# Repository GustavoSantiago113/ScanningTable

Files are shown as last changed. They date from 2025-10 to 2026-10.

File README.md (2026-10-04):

<div align="center">

# 3D Reconstruction of Small Objects

**Non-official implementation and adaptation of the paper: [Automated Low-Cost Photogrammetric Acquisition of 3D Models from Small Form-Factor Artefacts](https://www.mdpi.com/2079-9292/8/12/1441), from Collins et al., 2019**

**Note:** This implementation was performed in a **Linux** environment, with GPU with CUDA acceleration.

</div>

---

- [3D Reconstruction of Small Objects](#3d-reconstruction-of-small-objects)
- [Step 1 - Image Acquisiton hardware](#step-1---image-acquisiton-hardware)
- [Step 2 - Acquisition Software](#step-2---acquisition-software)
- [Step 3 - Taking Images](#step-3---taking-images)
- [Step 4 - Camera Geometry Estimation](#step-4---camera-geometry-estimation)
- [Step 5 - Dense Point Cloud Reconstruction](#step-5---dense-point-cloud-reconstruction)
- [Step 6 - Cropping](#step-6---cropping)
- [Step 7 - Point Cloud Registration](#step-7---point-cloud-registration)
- [Step 8 - Meshing](#step-8---meshing)
- [Step 9 - Texturing](#step-9---texturing)
- [Running the whole pipeline in one go](#running-the-whole-pipeline-in-one-go)

---

# Step 1 - Image Acquisiton hardware

For the table, I 3D modeled and printed a structure for it. It has a base and a top plate. You can find the models in the folder [3DFiles](3DFiles/). You can print it in the way you prefer, but I recommend using PLA, 3 layers of wall width, 20% fill, and 0.2mm layer height. To aid in the table movement, I added **3 2809 bearings.** To fix the motor in place, I used 2 3mm bolts.

The pseudo-random calibration pattern was made using a code in Python, available at the file [generate_pattern.py](utils/generate_pattern.py). It generates the pattern of a 130x130 mm square with 52 squares at each side, and saves as an image.

For the hardware, I used a 28BYJ-48 Stepper Motor with a ULN2003AN DIP-16 Driver. To connect with the phone and control the motor, I am using a Wemos D1 Mini ESP8266 Board. To power it, I am using a 9V power supply and a L7805 voltage regulator, with some capacitors. To connect everything, I made a custom PCB. The bill of materials, schematics and gerber files are in the folder [PCB](PCB/).

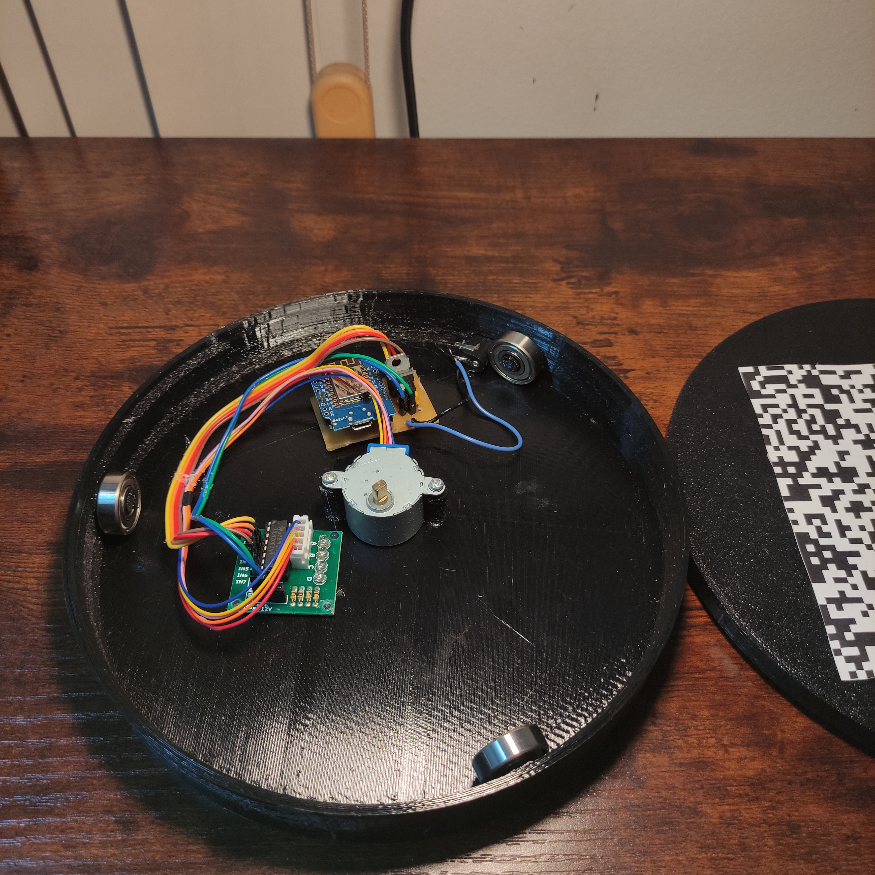
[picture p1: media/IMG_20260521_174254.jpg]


For the lights, I followed the same method as described by the paper, with a desk lamp at 20 cm perpendicullarly appart from the rotating plate **using a cold, white LED**.

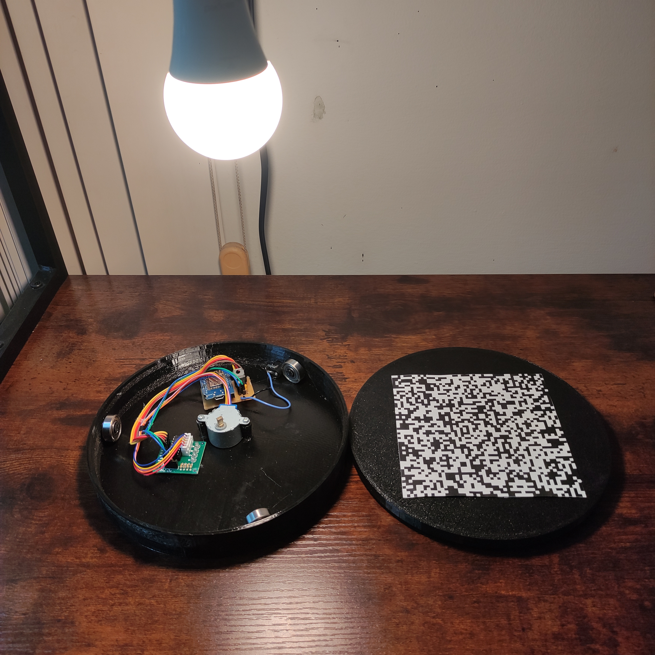
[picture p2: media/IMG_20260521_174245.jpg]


To support the phone, I used the tripod design found in ThingIverse: https://www.thingiverse.com/thing:2423960/files . The files are also in the [3DFiles folder](3DFiles)

# Step 2 - Acquisition Software

The script to run the ESP8266 is available at [ESP8266.ino](ESP8266\ESP8266.ino). The number of rotations is fixed on 36 (10 degree interval). The ESP creates a WebServer, with a Wi-Fi name and a password. The app sends requests to the ESP, such as: `start`, `stop`, and `continue`. The ESP sends the command `waiting` to the app so it knows when to take the picture.

The [app](scanning_table_app) was made in *Flutter* and **tested on an Android device only**. It has a initial page, only allowing to move to the next page (taking pictures) when the cellphone is connected to the ESP. To start scanning the user first must to choose the folder where the images are going to be saved. After that, the user can click on `Scan` and the app + ESP does the rest automatically. If something goes wrong, the user can click on `stop`, and the operation will be stopped.

Each photo is saved as `<scan>_stop_<stop>_<timestamp>.jpg`, e.g. `01_stop_03_20260703_163620.jpg` - `<scan>` numbers each full rotation sequence within the current app session (`01` for the first press of `Scan`, `02` for the second, and so on) and resets back to `01` every time the app is (re)started, so photos from different scans in the same folder never collide or get mixed up.

The camera settings in the app are following the paper description:
- Apperture of f/1.2;
- Shutter speed of 1/4s;
- ISO 200;

**Important reminder: to connect with the ESP, the mobile data must be turned off**

# Step 3 - Taking Images

The camera was positioned a little bit different than described in the paper. Instead of at 40 degrees to the table and at 25cm distant, as describred, the images were took framing the whole calibration pattern, at less than 40 degrees. The reason for this is that phones have different focals, meaning that the images from different phones will become different, even if you keep the same parameters. *When doing this on your phone, try to make the board occupy the maximum of the image as possible and at low angles*. See an example of the virtual image, where you must try to mimic its position in the real picture:

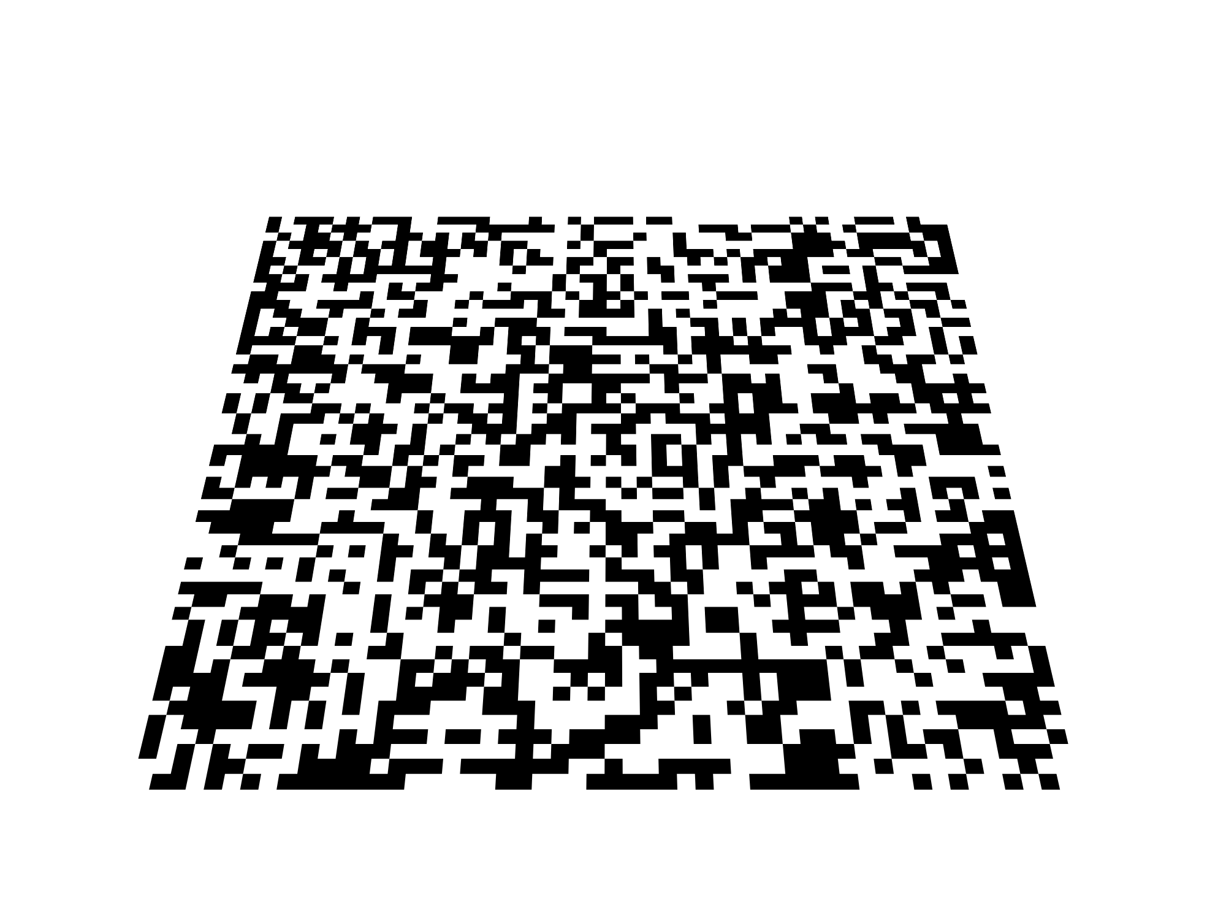
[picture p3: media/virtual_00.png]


Just like in the paper, I took some sets of different angles of the object (a 32mm scale minitature painted by me). The sets are in the folder [images](images/). Some examples:

**<center>Set 1:**

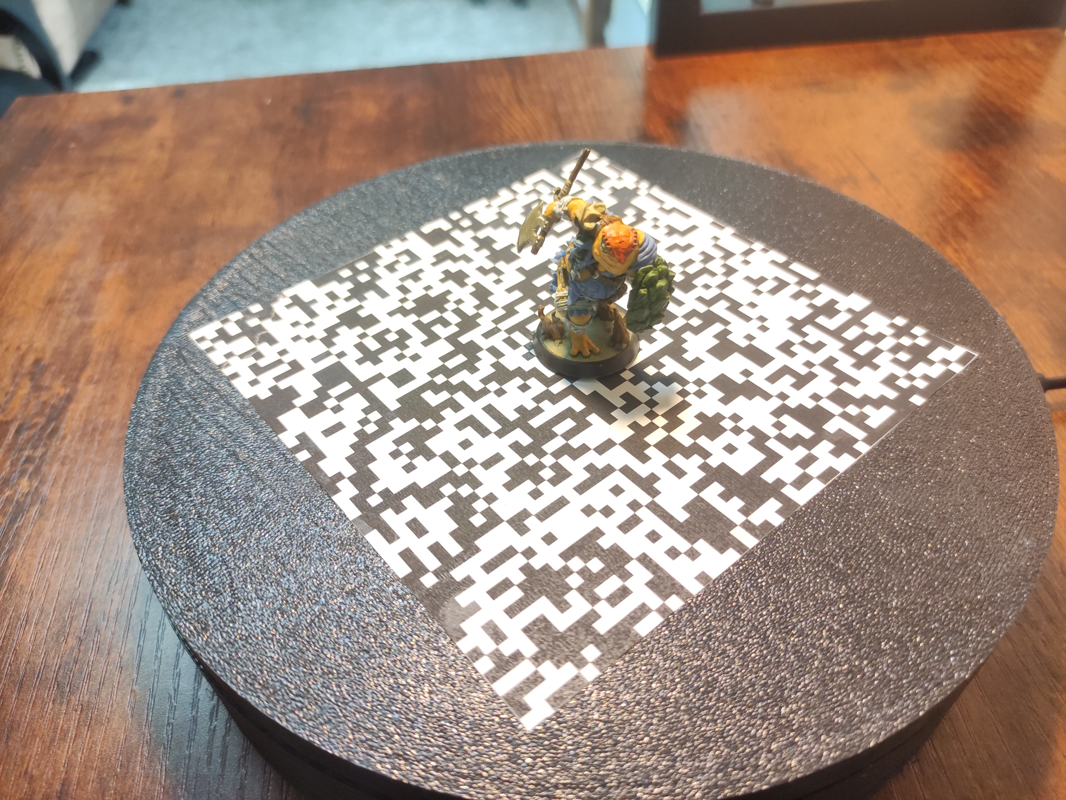
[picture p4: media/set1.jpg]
</center>

**<center>Set 2:**

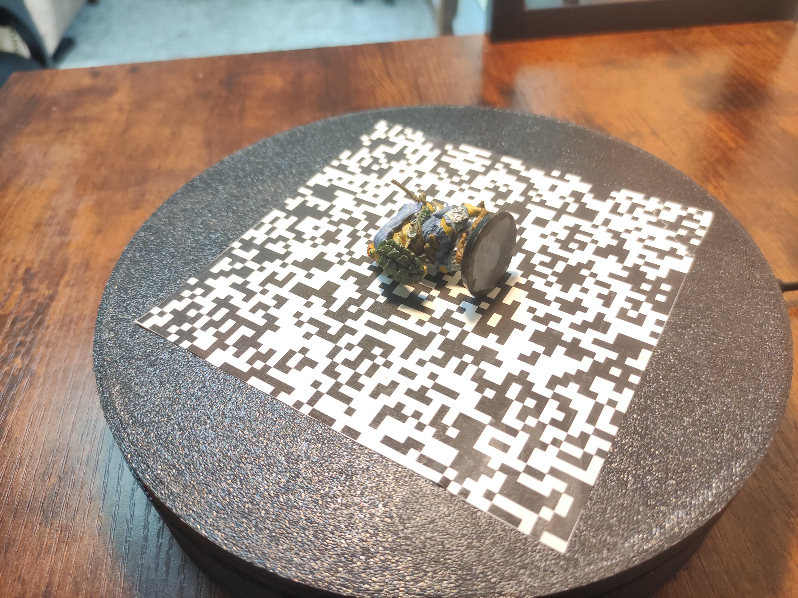
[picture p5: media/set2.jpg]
</center>

**<center>Set 3:**

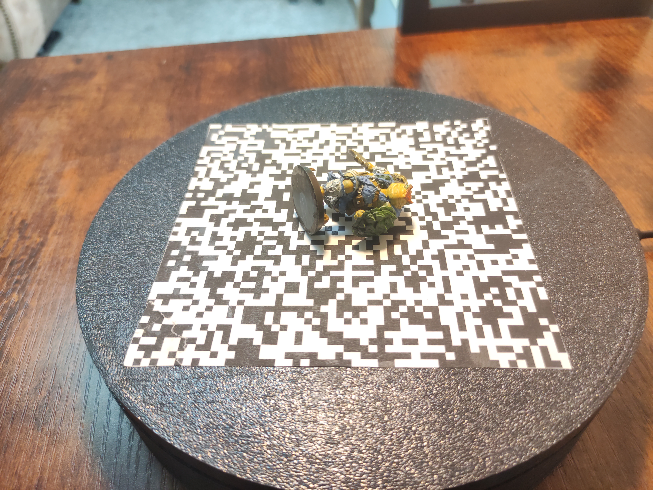
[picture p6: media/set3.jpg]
</center>

# Step 4 - Camera Geometry Estimation

Implemented in [camera_geometry_estimation.ipynb](camera_geometry_estimation.ipynb), using [pycolmap with cuda](https://github.com/colmap/pycolmap) for feature extraction, matching and bundle
adjustment - SIFT extraction and matching both run on the GPU (`pycolmap.Device.cuda`) explicitly,
not just via bundle adjustment's own solver, trading a small amount of run-to-run reproducibility
(GPU SIFT's extraction order isn't as tightly controlled as the CPU path's) for materially faster
extraction/matching; see `colmap_calibration.build_database`'s own docstring if byte-identical
results across runs matter more than that speed. The pipeline follows the paper: a sequence of virtual "photographs" of the calibration
plate is rendered from known viewpoints (paper spec: 12 views, 30&deg; apart, 45&deg; elevation;
the notebook defaults to 24 views/15&deg; steps for denser real-photo coverage - see its parameters
cell to reproduce the literal paper spec), registered with COLMAP at their exact known
intrinsics/pose, and used as a fixed calibration model that the real photographs are localised
against via incremental bundle adjustment (`fix_existing_frames` + `constant_cameras` keep the
virtual poses/intrinsics fixed throughout; only the real cameras are refined). A final
retriangulation pass (using every registered camera, not just the virtual ones) then fills out the
sparse point cloud with the artefact's own geometry, not just the calibration plate, before the
virtual photographs are removed, leaving calibrated real cameras plus a sparse point cloud ready
for dense reconstruction.

Not every real photograph is guaranteed to register - the notebook reports how many did, and is
intentionally bounded to a fixed runtime (`MAX_RUNTIME_SECONDS`, `MAX_REG_TRIALS=1`) rather than
retrying indefinitely. Registration also includes plausibility filters (implausible
camera-to-plate distance, near-duplicate positions from COLMAP's linear solver failing on a
poorly-conditioned planar-target fit) that discard failed estimates rather than keep them.

`reconstruct.py` adds a few robustness steps on top of the notebook:

- **Focal-length prior from the plate.** A homography between several photos and the flat pattern
  gives the real camera's focal length (Zhang's plane constraints). EXIF is only the fallback.
- **Resolution search.** Registration is retried at long edges from 1500px up to `--max-long-edge`
  (smallest first) until more than 30 photos register. If nothing registers at any size, the
  search runs again with exact (brute-force) matching.
- **Orbit check.** An attempt whose cameras' heights spread more than 40mm is rejected, because one
  camera on a turntable traces a horizontal circle.
- **Orbit filling.** Photos COLMAP still couldn't place are posed by rotating their registered
  neighbours about the fitted turntable axis. This uses the stop index in the file name
  (`..._stop_07_...jpg`).

Dense stereo still runs at `--max-long-edge`: the calibrated cameras are rescaled to that size.

# Step 5 - Dense Point Cloud Reconstruction

Implemented in [dense_reconstruction.ipynb](dense_reconstruction.ipynb). The paper uses CMVS/PMVS
(Furukawa's clustering-views-for-multi-view-stereo toolchain) for this step. That toolchain has no
pip package, is unmaintained, and COLMAP's own docs describe it as superseded by COLMAP's own dense
pipeline - **PatchMatchStereo** (per-image depth/normal maps) followed by **StereoFusion** (merging
those into one point cloud) - which this notebook uses instead, via the same `pycolmap` library
already used for calibration.

The pipeline: load Step 4's calibrated real cameras and reuse the exact downscaled photographs it
already calibrated against (`outputs/<set>/work`, no separate re-downscale needed) &rarr; undistort
into a COLMAP dense workspace &rarr; PatchMatchStereo for per-image depth/normal maps &rarr;
StereoFusion into one dense, coloured point cloud &rarr; restrict to a rough region of interest
around the artefact (not the paper's dedicated cropping stage, which comes later) &rarr; attempt to
downsample towards target point densities (points per mm&sup2; of the ROI's bounding-box surface
area, standing in for actual surface area until a mesh exists).

**On target density**: this step was scoped for 100 and 300 points/mm&sup2;. Validated on `set_1`
(35 photos, downscaled to 2000x1500 as Step 4 left them), the achieved density came out to
**~6 points/mm&sup2;** - one to two orders of magnitude below either target. The notebook keeps
both targets as explicit parameters and reports the honest gap (via
`dense_reconstruction.downsample_to_density`'s `reached_target=False` path) rather than silently
substituting a different number or fabricating points a camera never actually resolved. This is a
property of the input photos (phone camera, ~20-25cm working distance, downscaled for tractable
runtime) more than the algorithm - raising Step 4's `MAX_LONG_EDGE` (more pixels on the artefact per
photo) and/or taking more, closer photos would likely close some of that gap, at the cost of a much
longer `PatchMatchStereo` runtime (full 4000x3000 photos measured ~60-90s/image on the dev GPU,
vs. ~35 minutes total for all of `set_1` at 2000x1500). Even though the poits density were not as high as stated in the paper, the reconstruction level of details is *impressive*.

# Step 6 - Cropping

Implemented in [cropping.ipynb](cropping.ipynb). An axis-aligned crop box with x/y extent equal
to the calibration pattern's own size (130&times;130&nbsp;mm, centred at the world origin, since
the calibration model is defined at z&nbsp;=&nbsp;0), and a **fixed** z lower-limit of
2&nbsp;mm above the turntable.

The paper's own method for the lower limit is a *search*, not a fixed offset: slide a 1mm slab
upward from 2mm above the turntable, averaging point luminosity, until it crosses a threshold -
below that z is dark supporting material, above it the lighter artefact. That's the right method
for a setup that actually hides the object on dark foam. This implementation's own captures
(`set_1`, `set_2`) don't use any, though: measured directly against the real data, the printed
pattern is one dominant, bright, neutral-grey point mass right at z&nbsp;=&nbsp;0, and the
artefact's own material begins immediately above it (over a 100x point-count drop between z=0 and
z=1mm) - there's no separate dark material to search for, so the fixed 2mm offset is used
directly instead. The luminosity search (`cropping.find_lower_z_limit`) is still implemented and
correct; it just isn't called by `reconstruct.py`'s pipeline by default any more, because on this
project's own real data it actively mis-fired - see the next bullet.

Four things came up validating this against real data (`set_1`-`set_3`) that the paper's setup
doesn't need to deal with:

- **Level the turntable tilt**. Not in the paper, added for this implementation: the
   calibration model fixes the pattern at world Z&nbsp;=&nbsp;0 by construction, but the *real*,
   physically captured turntable doesn't have to be level in that same frame, and the z-based
   crop assumes it is. A RANSAC plane fit finds the real pattern/turntable plane and the
   cloud is rotated so that plane sits back at Z&nbsp;=&nbsp;0.
- **A Step 4 orientation bug.** This implementation's real-camera reconstruction comes out mirrored
  through the z&nbsp;=&nbsp;0 plane - the artefact reconstructs *below* the turntable instead of
  above it, almost certainly Step 4's own coplanar-target pose ambiguity (see
  `plate_geometry.look_at_origin`'s docstring) resolving to the wrong sign for this rig.
  `cropping.correct_z_axis_inversion` negates z as a workaround at the data-consumption end so the
  rest of the crop logic (written straight from the paper, which assumes the artefact sits above
  the turntable) applies correctly. The proper fix belongs in `colmap_calibration.py`'s pose
  disambiguation, not here.
- **A z upper-limit isn't in the paper**, but was added here because this implementation's dense
  reconstruction consistently leaves one small clump of disconnected debris floating well above
  the artefact (likely a specular-highlight fusion ghost) - visible as a gap in point density
  between the artefact's own tapering mass and that clump. `cropping.find_upper_z_limit` cuts at
  the first sufficiently-thick run of near-empty slices above the lower limit. It's a narrow,
  generic density-gap heuristic, not a general outlier remover.

# Step 7 - Point Cloud Registration

Implemented in [point_cloud_registration.ipynb](point_cloud_registration.ipynb). This covers the
paper's full Section 2.4.4 - registration *and* the confidence-weighted merge it also describes,
since the paper treats both under one heading. Each of `set_1`-`set_3` was captured with the
object resting differently on the turntable, so Step 6's three cropped point-clouds are genuine
partial views, each in its own independent frame, that need combining:

1. **Coarse alignment** - paper spec: Super4PCS. No maintained pip package or Python binding
   exists for either 4PCS or Super4PCS, so `utils/registration.py`'s `coarse_align` implements the
   same family of algorithm from scratch: a RANSAC search over congruent point triples (matching
   pairwise distances, scored by largest-common-pointset overlap) rather than Mellado et al.'s
   specific coplanar-4-point/smart-indexing formulation - that indexing is what makes Super4PCS
   *fast*; it doesn't change what a correct coarse alignment looks like.
2. **Fine alignment** - a Weighted ICP (`weighted_icp`), exactly as described: each nearest-
   neighbour correspondence is weighted by the product of its two points' confidence values
   (Equation 3), so precisely-reconstructed points dominate the fit.
3. **Confidence** (Equation 2) needs a per-point surface normal, which Step 5's `pycolmap`-based
   dense reconstruction doesn't preserve (its `Reconstruction` object drops the photo-consistency
   normals PatchMatchStereo/StereoFusion compute internally). `estimate_normals` substitutes a
   standard PCA-over-local-neighbours normal, oriented outward from the cloud's own centroid.
4. **Merge** (Equation 4): once registered, close point pairs across clouds are confidence-
   weighted-interpolated into one rather than kept as two redundant, possibly conflicting points;
   unique points are kept as-is. This also does this implementation's pruning - there's no separate
   pruning stage.

# Step 8 - Meshing

Implemented in [meshing.ipynb](meshing.ipynb) via `utils/meshing.py`, following the paper's
Section 2.4.5 directly:

> Following the point-cloud registration and merging operations described above, the points
> require connecting to form a surface mesh before texturing can be applied. Poisson surface
> reconstruction was used for this stage and was chosen for its relative simplicity and
> reliability. Some care is needed to avoid loss of detail on inscribed surfaces. We found that
> an octree depth of 14 gave a good compromise, retaining the detail of the inscriptions with a
> tractable computational complexity.

Poisson reconstruction itself runs via `pycolmap.poisson_meshing`, COLMAP's own binding around
Kazhdan's reference PoissonRecon implementation - not `open3d`, which this implementation used
originally (`open3d` is still used for point-cloud/mesh I/O and cleanup). Two things came up
switching to it, both specific to running on this project's WSL development machine rather than
algorithmic:

- **`num_threads` has to stay pinned at 1.** Left at COLMAP's own default (`-1`, all cores),
  `pycolmap.poisson_meshing` hangs on this machine - a trivial depth-6 smoke test went from 0.9s
  at `num_threads=1` to 43s at full multithreading, and a depth-14 run at realistic point-cloud
  scale (250,000 points) was still running after 10+ minutes (pegging ~18 of the machine's 20
  cores) before being killed. This mirrors an already-known problem: `pymeshlab`'s own Poisson
  filter was tried and rejected earlier in this project for the same class of issue (see the
  Texturing section below) - sustained multithreaded load repeatedly correlating with this WSL
  instance's own instability. Pinned to `num_threads=1`, the same depth-14/250k-point run finishes
  in ~70.6s, against ~128s for the `open3d` path it replaced - faster as well as reliable.

- **COLMAP's own trim step corrupts output at this project's data scale.** `PoissonMeshingOptions`
  exposes a `trim` parameter (a density threshold for its own low-confidence-vertex removal), but
  every nonzero value tested - including deliberately tiny ones - produced NaN and huge-magnitude
  (>1000, against a true bounding box of order 100mm) vertex positions. This isn't a case of
  picking a bad absolute number: on a realistic mm-scale test cloud, `trim=10.0` (the library's
  own default) corrupted 86% of output vertices, while `trim=1.0` on the *same* cloud was
  completely clean - the correct value is scale/density-dependent in a way this build gives no
  safe way to discover in advance, and a wrong one corrupts silently rather than erroring.
  `trim=0.0` (disabling the step outright) was the only value verified clean at every scale
  tested, so that's what's hardcoded - which also means the returned mesh carries no per-vertex
  density estimate the way `open3d`'s binding did.

One thing came up building the original `open3d`-based version against real data, and still
applies:

- **Poisson reconstructs a phantom "bubble" surface.** Poisson fits one *global* implicit
  function across the whole point-cloud, so even a handful of points far from everything else -
  each still gets a plausible local normal - can pull that function's zero-level-set out into a
  sizeable, completely disconnected surface floating in empty space. Diagnosed on this implementation's
  own merged cloud: 67,805 of 67,820 points form one connected component at a 1.5mm radius, and
  the rest are 1-4-point fragments (registration/fusion debris, not real geometry) scattered
  elsewhere. `meshing.remove_isolated_points` removes those from the *point-cloud*, before Poisson
  ever sees them, rather than trying to identify and trim the mesh it produces from them
  afterwards - which needs the (expensive) reconstruction to have already run once just to find
  out.

- **Thin, sparsely-sampled structures balloon into a "blob" instead of meshing thin.** This is a
  different failure from the bubble above - it happens even on a clean point-cloud with no
  disconnected debris. Poisson's single global implicit function has to produce *something*
  wherever point density drops, and where it drops enough (a narrow base, a thin protrusion),
  the reconstructed surface doesn't taper down with it - it extrapolates past the last real point
  and rounds out into a smooth bulge with nothing behind it. Diagnosed on a real scan with a
  sparsely-sampled base (using the original `open3d`-based Poisson, which still returned a density
  estimate): the raw mesh's z-range extended ~16mm past the point-cloud's own lowest point, and
  every one of those extrapolated vertices fell in the bottom ~3.5% of Poisson's own per-vertex
  density estimate. Low density isn't the same as thin-but-real, though - it flags *unsupported
  extrapolation* specifically. Since switching to `pycolmap.poisson_meshing` gives up that density
  estimate (see above), `meshing.trim_unsupported_vertices` now flags the same failure mode with a
  differently-sourced signal instead: each mesh vertex's KD-tree distance to the nearest real point
  in the input cloud, dropping the `quantile` fraction farthest from any real point (default
  `quantile=0.02`) - the two metrics should behave similarly (both are low exactly where the input
  cloud's own support is thin), but this specific metric/threshold pairing hasn't yet been
  re-validated against real captures the way the density-based version was. Cutting vertices out of
  the mesh's middle leaves small disconnected shell fragments along the cut;
  `meshing.remove_small_mesh_components` clears those by keeping only connected triangle components
  of at least `min_triangles` (default `100`) - on the scan above, 1,522 components dropped to
  ~130, and the ones removed made up under 1% of the mesh's total triangles.

# Step 9 - Texturing

Implemented in [texturing.ipynb](texturing.ipynb) via `utils/texturing.py`, following the
paper's Section 2.4.6: project the original photographs onto Step 8's mesh using the camera
positions from Step 4's calibration. Each registered real camera is carried through this
implementation's own Step 4 &rarr; Step 8 chain into the mesh's common frame - this implementation's version
of the paper's "VmnMn" (camera Vmn transformed by the per-acquisition model-matrix Mn):

- **The z-axis correction has no valid rigid-body camera analogue.** Step 6 corrects the
  *points* by negating z outright (`cropping.correct_z_axis_inversion`) - a reflection, not a
  rotation, so there's no way to move a *camera* the same way and still call the result a
  physically normal camera. `texturing.flip_z_camera_pose` derives the (improper, but
  correctly-reprojecting) substitute instead: composing the original camera rotation with the
  z-flip *on the right* reprojects corrected-frame points onto exactly the same pixels the
  original, unmirrored camera always did, even though the resulting matrix has det = -1. This
  was validated against this implementation's own real cameras, not just derived on paper: repositioned
  into the mesh's common frame, all 100 registered real cameras across the three sets look at
  the mesh's own centroid to within about 6-10&deg; (the notebook's own sanity-check step) -
  before landing on this formula, they were off by ~173&deg;, i.e. facing almost exactly
  backwards.
- **Step 7's registration transform** carries the camera the same way
  `registration.apply_transform` carries points (`texturing.compose_with_registration`).

The paper's own tool for this step is MeshLab (via UV-atlas texturing from registered
cameras). `pymeshlab`'s equivalent filter turned out to be broken under headless/server
execution in this environment (a long-standing, version-spanning upstream issue, not specific
to this setup), so this implementation instead uses `open3d` (already a project dependency,
`meshing.py`) to project every registered, undistorted photo directly onto the mesh and paint
each *vertex* with the occlusion-aware, multi-view-blended result - not a UV-mapped texture
atlas, but real photographic colour, correctly occlusion-tested per camera via `open3d`'s own
`RaycastingScene` (Embree-backed, CPU-only). Two things needed correcting empirically before
this was trustworthy, not just plausible-looking - both documented in
`texturing.texture_mesh_vertex_colors`'s own docstring:

- **Ray direction.** Casting the occlusion ray *from* each vertex *towards* the camera
  routinely self-intersects an adjacent triangle at t &asymp; 0 ("shadow acne") - this mesh is
  not watertight or edge-manifold (`mesh.is_watertight()` is `False`), so no fixed offset
  reliably escaped it. Casting *from the camera towards* the vertex instead avoids the problem
  entirely (the ray origin is never near the mesh surface) and doubles as a proper z-buffer-style
  visibility test.
- **Occlusion tolerance.** Initially rejected a vertex whenever the ray hit anything before
  reaching it, which - audited directly against this implementation's own mesh - was rejecting even
  vertices whose normals point almost exactly at the camera. Tracing a few of those hits showed
  real geometry several mm to multiple cm away, not numerical noise: this is a small,
  geometrically complex hand-painted miniature (limbs, weapon, folds), photographed at one fixed
  camera elevation per set, so most surface points genuinely are only visible from a narrow slice
  of the ~100 photos across all three sets. A wider tolerance (1.5&nbsp;mm - comfortably above
  this mesh's own sub-mm surface noise, well below genuine occlusion distances) fixed the
  false rejections without papering over real ones; final coverage is 77% of vertices coloured
  directly from a photo, the rest kept their Step 7/8 point-cloud colour rather than being left
  uncoloured.

# Running the whole pipeline in one go

Steps 4-9 are also available as a single script, [reconstruct.py](reconstruct.py), instead of
six notebooks run one at a time by hand. It auto-discovers every set folder under `images/`
(no `SET_NAME` to edit per run) and drives camera geometry estimation through texturing
end-to-end, set by set, then registers, meshes, and textures whatever sets made it through:

```
python reconstruct.py
```

A few things this script does differently from the notebooks it consolidates, all by design
rather than oversight:

- **No plots.** The notebooks' `matplotlib`/`open3d` visualisations are for inspecting one run
  interactively; this script only logs text - including the same "something might be wrong"
  signals the notebooks otherwise show as a chart to eyeball (a low camera-registration rate, a
  weak coarse-alignment score, ICP not converging, low vertex-photo coverage, and so on) as
  `logging.warning` calls instead.
- **A bad set doesn't sink the run.** Camera geometry, dense reconstruction, and cropping run
  per set inside a `try`/`except`; a set that fails is logged and skipped, and registration/
  meshing/texturing proceed with whatever sets are left (at least one has to succeed).
- **Most intermediates never touch disk.** Cropped points, the merged cloud, the mesh, and each
  set's registration transform stay as in-memory Python objects passed straight from one stage
  to the next, rather than round-tripping through the PLY/JSON files separate notebooks need.
  Only what COLMAP's own file-based API requires (its database, plus several reconstruction/
  dense-workspace directories) still lands on disk mid-run.
- **Downscaling is optional.** `--max-long-edge` changes the notebooks' default of 3000px;
  `--no-downscale` processes the original photographs at full resolution.
- **Cleanup always runs once texturing finishes**, by default leaving only
  `outputs/mesh/mesh.ply` and `outputs/textured/textured.ply`. `--keep-intermediates` widens
  what survives to one plain `.ply` per major stage instead - `<set>/sparse.ply` (Step 4),
  `<set>/dense.ply` (Step 5), `<set>/cropped/cropped.ply` (Step 6), `merged/merged.ply` (Step
  7) - written specifically for the flag, since the pipeline itself never puts these on disk
  otherwise. COLMAP's own databases and dense workspaces are cleaned up either way - the flag is
  for inspecting the point-cloud pipeline stage by stage, not for keeping every byte a run
  touched.

**Requires a CUDA GPU** (Step 5, PatchMatchStereo, has no CPU fallback) - the script checks for
one via `nvidia-smi` at startup and logs a warning rather than failing silently deep into the
first set if none is found. See `python reconstruct.py --help` for the full list of overrides
(sets to include, reference set, thread count, random seed, log level, ...).

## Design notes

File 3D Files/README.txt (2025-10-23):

1x Base Plate
1x Gear Plate
3x Leg
1x Motor Gear
1x Phone Adapter
1x Phone Holder
1x Phone Link
3x Pin
3x Screwnut
1x Top Plate

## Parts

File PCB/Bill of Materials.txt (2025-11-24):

Wemos D1 Mini ESP8266 Board x 1	
28BYJ-48 Stepper Motor + ULN2003AN DIP-16 Driver and Wires x 1	
L7805 1.5A Fixed 5V TO-220 Voltage Regulator x 1
100uF 16V Aluminum Electrolytic Capacitors x 1	
100nF Through Hole Ceramic Capacitors x 1
9V power supply x 1
DC power jack/connector x 1

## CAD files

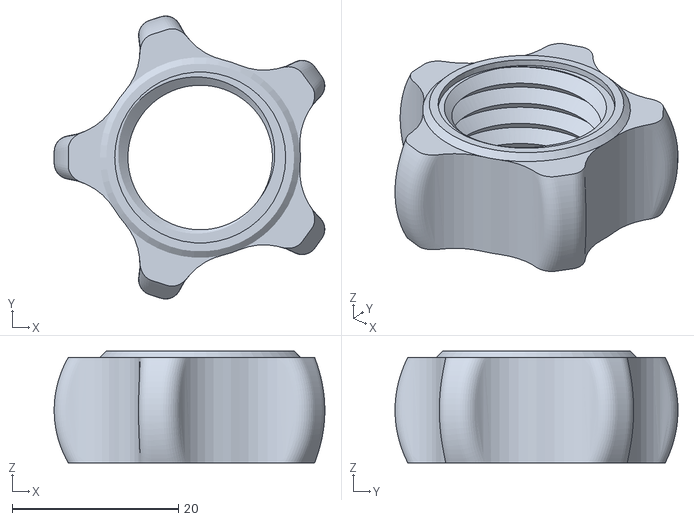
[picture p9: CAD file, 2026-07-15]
3DFiles/KNOB.STL
32.6 x 34.1 x 13.5

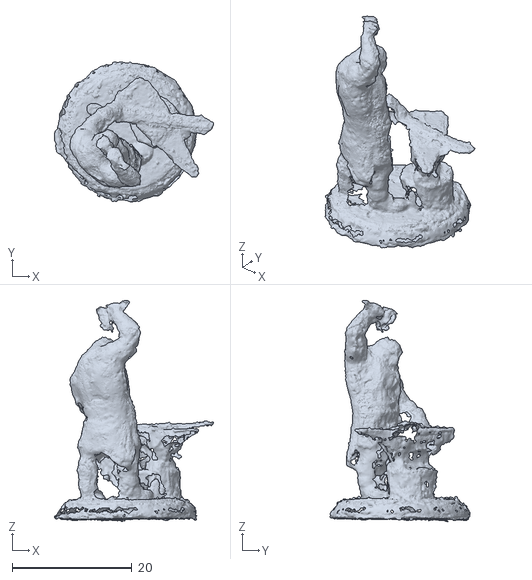
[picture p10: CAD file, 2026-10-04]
outputs/mesh/mesh.ply
26.6 x 23.4 x 36.8

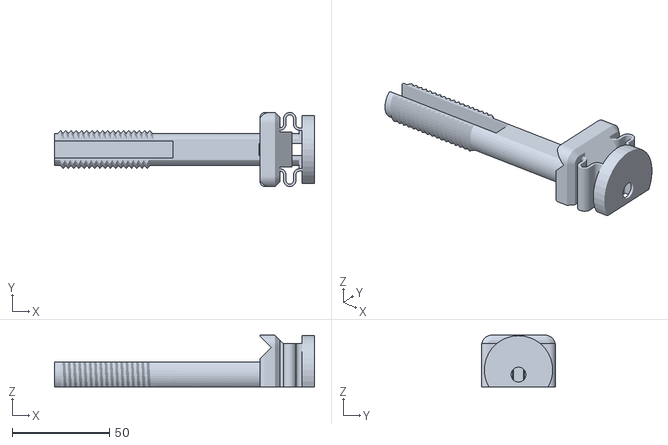
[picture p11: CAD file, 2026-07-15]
3DFiles/Base.stl
133.5 x 38.1 x 26.7

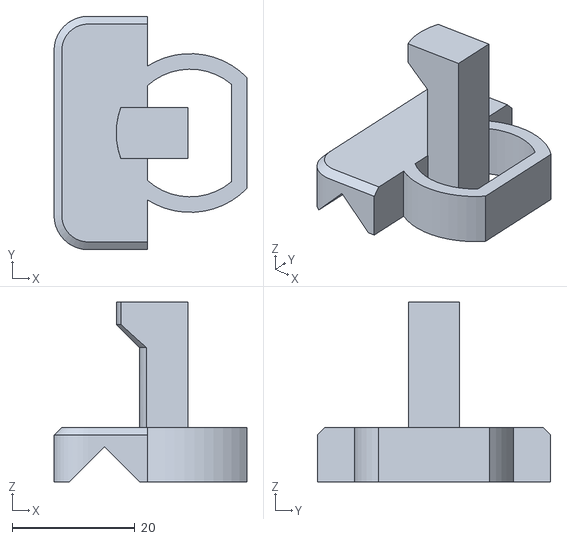
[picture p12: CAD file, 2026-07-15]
3DFiles/SLIDER.STL
31.5 x 38.1 x 29.3

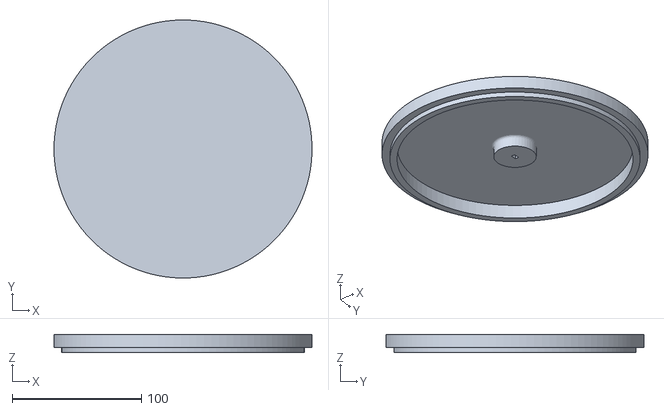
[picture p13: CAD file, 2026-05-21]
3DFiles/Rotating_Plate.stl
200.0 x 200.0 x 14.0

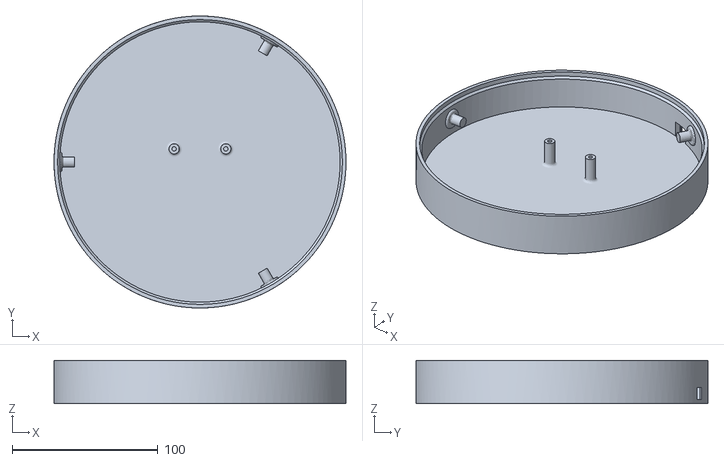
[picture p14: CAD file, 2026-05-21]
3DFiles/Base_plate.stl
200.0 x 200.0 x 29.8

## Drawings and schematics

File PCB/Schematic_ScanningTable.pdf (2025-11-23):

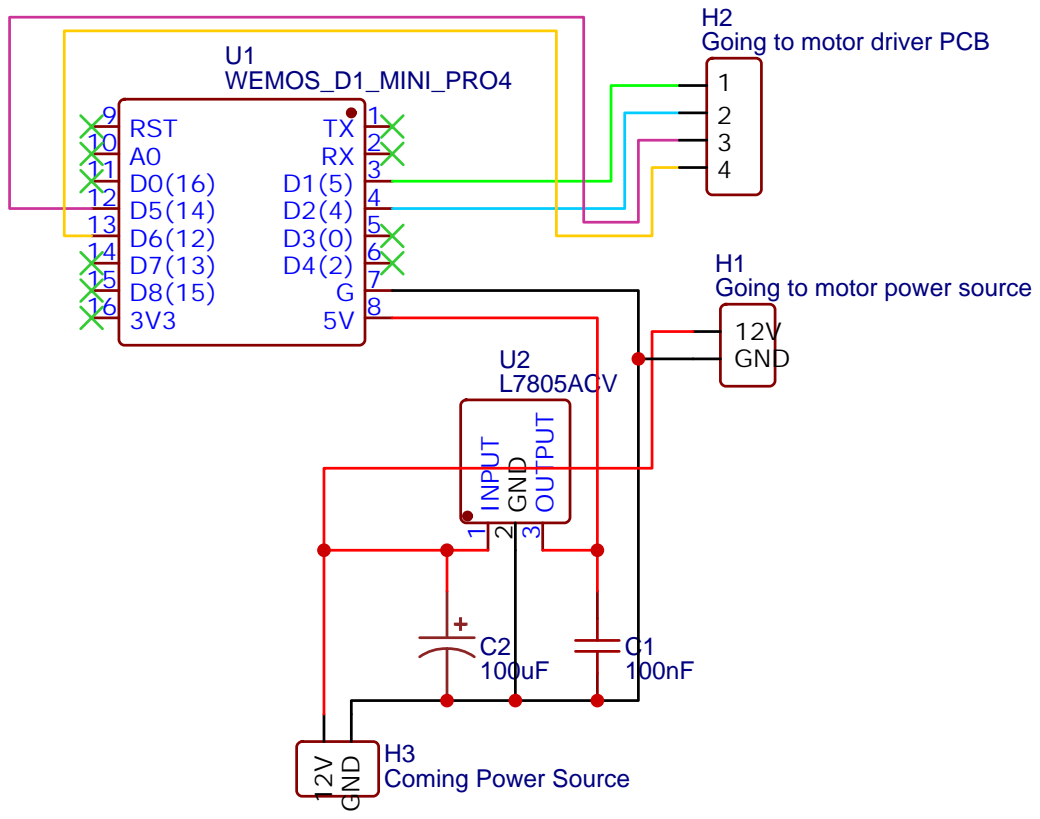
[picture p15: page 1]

Drawn By: Gustavo Santiago

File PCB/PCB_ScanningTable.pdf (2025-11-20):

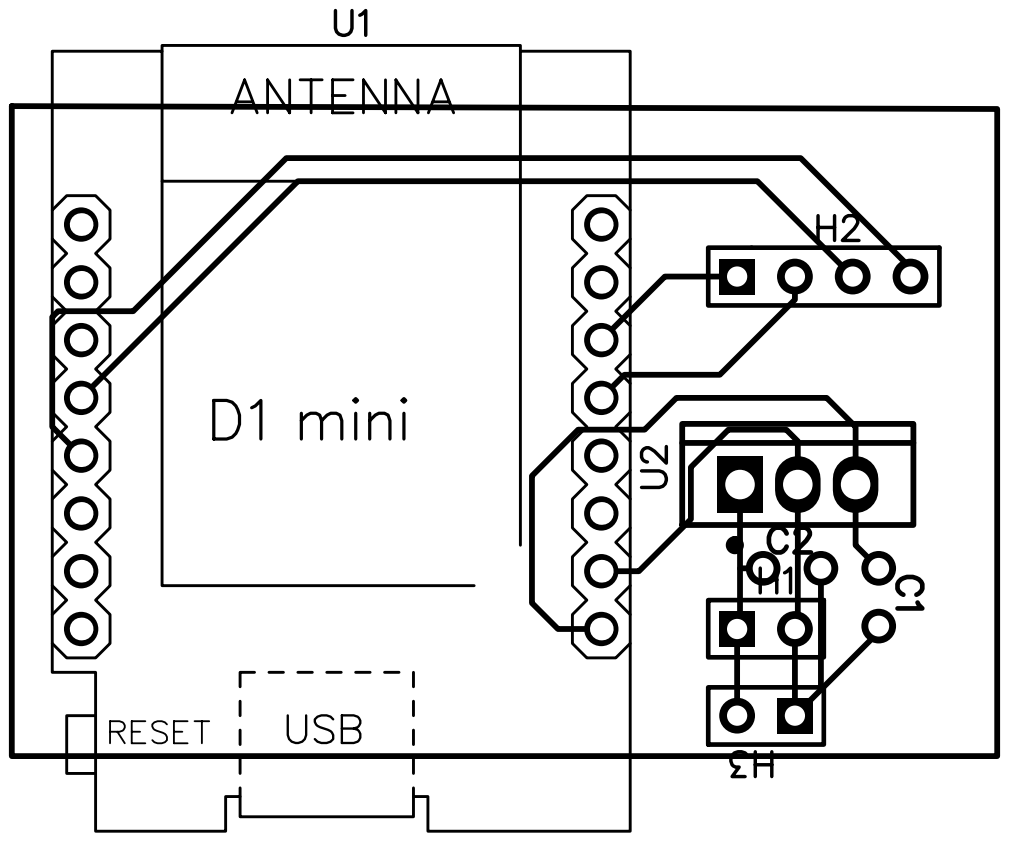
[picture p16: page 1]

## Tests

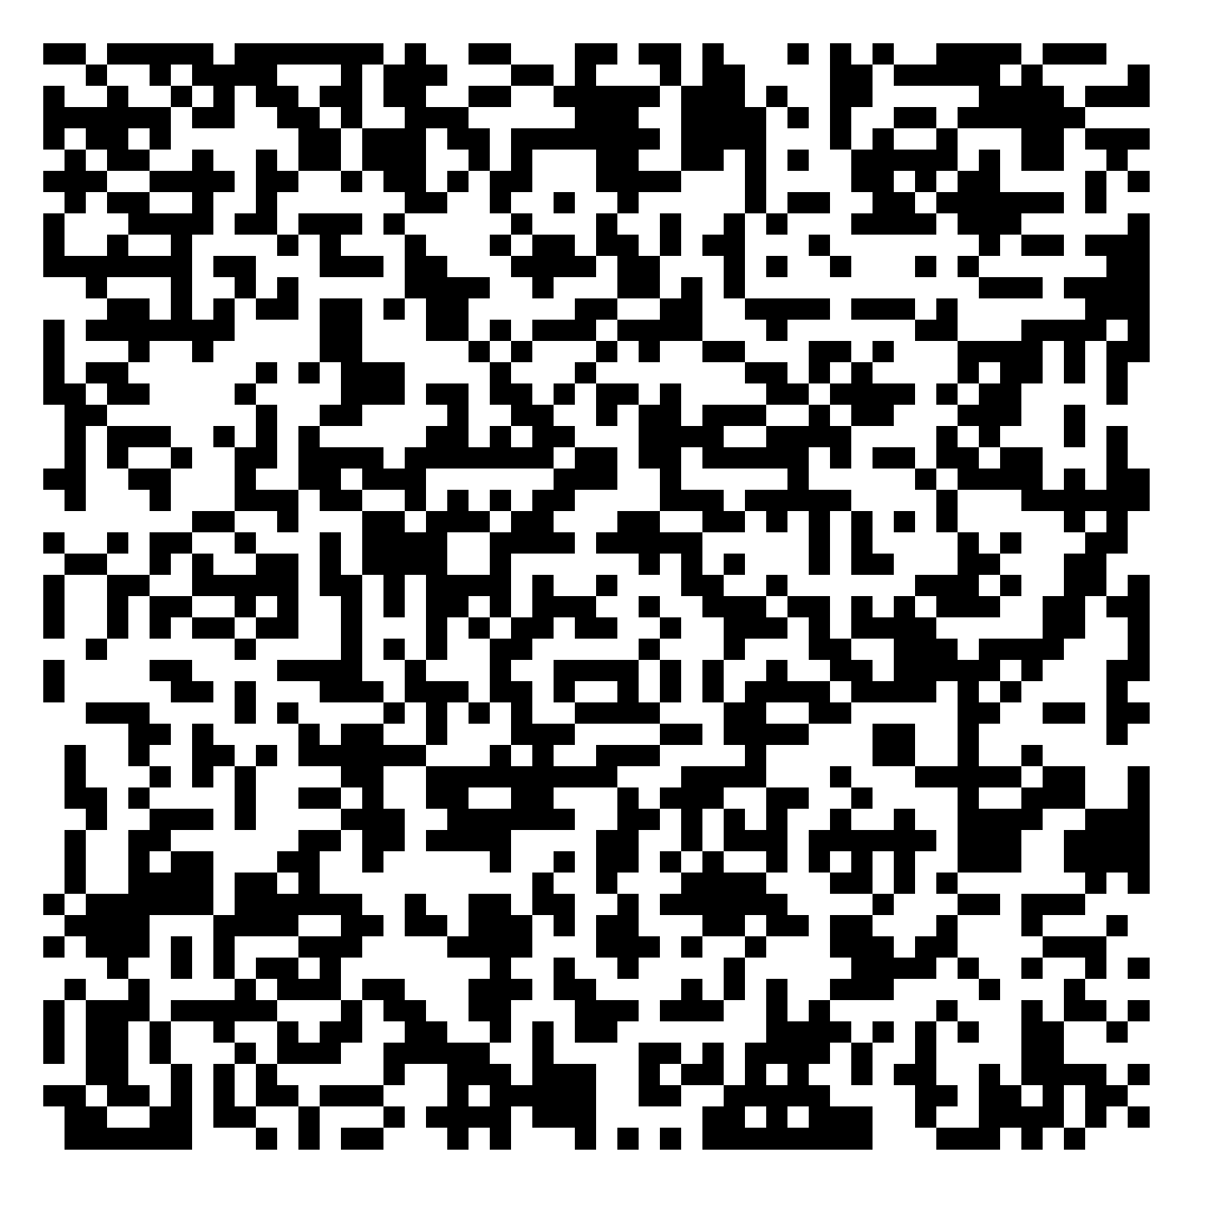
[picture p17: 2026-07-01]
pseudo_random_calibration_pattern.png

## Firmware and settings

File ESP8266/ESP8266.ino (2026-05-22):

#include <Arduino.h>
#include <ESP8266WiFi.h>
#include <ESP8266WebServer.h>
#include <Stepper.h>

// --- Wi-Fi Access Point ---
const char* ssid = "ESP_Motor_WS";
const char* password = "12345678";

#define IN1 5   // D1
#define IN2 4   // D2
#define IN3 14  // D5
#define IN4 12  // D6

#define STEPS_PER_REV 2048
Stepper stepper(STEPS_PER_REV, IN1, IN3, IN2, IN4);

// --- Motion tuning ---
// Microsecond delay between individual micro-steps (increase to slow down)
const unsigned int STEP_DELAY_US = 2000; // was 1000

#define DEFAULT_STOPS 36

// --- HTTP Server ---
ESP8266WebServer server(80);

// --- Motor control state ---
bool running = false;
bool waitingForContinue = false;
int totalStops = 0;
int currentStop = 0;
long stepsPerStop = 0;

// --- Rotation (full turn) state ---
bool performingRotation = false;
long rotationStepsRemaining = 0;
int rotationDir_global = 1;
int lastDir = 0; // global last direction (1 or -1)

// --- Helpers ---
void sendJson(const String &json, int code = 200) {
  server.sendHeader("Access-Control-Allow-Origin", "*");
  server.sendHeader("Access-Control-Allow-Methods", "GET,POST,OPTIONS");
  server.sendHeader("Access-Control-Allow-Headers", "Content-Type");
  server.send(code, "application/json", json);
}

void sendOk(const String &msg = "OK") {
  server.sendHeader("Access-Control-Allow-Origin", "*");
  server.send(200, "text/plain", msg);
}

void moveOneSegment() {
  if (!running) return;

  if (currentStop < totalStops) {
    performSteps(stepsPerStop);
    currentStop++;
    Serial.printf("Reached stop %d/%d\n", currentStop, totalStops);

    // Notify app via status polling (waitingForContinue)
    waitingForContinue = true;
  } else {
    running = false;
    waitingForContinue = false;
    Serial.println("Sequence complete.");
  }
}

void performSteps(long nsteps) {
  if (nsteps == 0) return;

  int dir = (nsteps > 0) ? 1 : -1;
  if (dir != lastDir && lastDir != 0) {
    Serial.println("Direction change cooldown");
    delay(200);           // allow coils to de-energize
  }
  lastDir = dir;

  long todo = abs(nsteps);
  for (long i = 0; i < todo; i++) {
    stepper.step(dir);    // one micro-step
    delayMicroseconds(STEP_DELAY_US); // tuned delay between micro-steps
    yield();              // keep Wi-Fi / watchdog alive
  }
}

// Called repeatedly from loop() to perform an in-progress full rotation
void processRotation() {
  if (!performingRotation || rotationStepsRemaining <= 0) return;
  // Interrupt rotation if STOP was sent
  if (!running) {
    performingRotation = false;
    waitingForContinue = false;
    Serial.println("Rotation interrupted by STOP.");
    return;
  }

  // If direction changed since last stepping, allow cooldown
  if (rotationDir_global != lastDir && lastDir != 0) {
    Serial.println("Direction change cooldown");
    delay(200);
  }
  lastDir = rotationDir_global;

  // Step in small chunks so we don't block the server for too long
  long chunk = (rotationStepsRemaining < 200) ? rotationStepsRemaining : 200;
  for (long i = 0; i < chunk; i++) {
    stepper.step(rotationDir_global);
    delayMicroseconds(STEP_DELAY_US);
    yield();
    // Check for STOP during chunk
    if (!running) {
      performingRotation = false;
      waitingForContinue = false;
      Serial.println("Rotation interrupted by STOP.");
      return;
    }
  }
  rotationStepsRemaining -= chunk;

  if (rotationStepsRemaining <= 0) {
    performingRotation = false;
    running = false;
    waitingForContinue = false;
    Serial.println("Full rotation complete.");
  }
}

// --- HTTP Handlers ---
void handleStatus() {
  String json = "{";
  json += "\"running\":" + String(running ? "true" : "false") + ",";
  json += "\"waitingForContinue\":" + String(waitingForContinue ? "true" : "false") + ",";
  json += "\"currentStop\":" + String(currentStop) + ",";
  json += "\"totalStops\":" + String(totalStops) + "}";
  sendJson(json);
}

void handleStart() {
  int turns = 0;
  if (server.hasArg("turns")) turns = server.arg("turns").toInt();

  // Always use DEFAULT_STOPS stops; ignore any stops parameter from client
  if (turns > 0) {
    const int stops = DEFAULT_STOPS;
    long totalSteps = (long)STEPS_PER_REV * (long)turns;
    stepsPerStop = totalSteps / stops;
    totalStops = stops;
    currentStop = 0;
    running = true;
    waitingForContinue = false;
    Serial.printf("START %d turns, %d stops (stepsPerStop=%ld)\\n", turns, stops, stepsPerStop);
    sendOk("STARTED");
    moveOneSegment();
  } else {
    server.send(400, "text/plain", "Invalid args. Use POST /start?turns=<n>");
  }
}

void handleContinue() {
  if (running && waitingForContinue) {
    waitingForContinue = false;
    sendOk("CONTINUING");
    moveOneSegment();
  } else {
    server.send(409, "text/plain", "Not waiting for continue");
  }
}

void handleStop() {
  running = false;
  waitingForContinue = false;
  Serial.println("Manual stop triggered.");
  sendOk("STOPPED");
}

void handleRotate() {
  if (running || performingRotation) {
    server.send(409, "text/plain", "Already running");
    return;
  }

  int turns = 1;
  if (server.hasArg("turns")) turns = server.arg("turns").toInt();
  if (turns <= 0) {
    server.send(400, "text/plain", "Invalid turns. Use POST /rotate?turns=<n>");
    return;
  }

  long totalSteps = (long)STEPS_PER_REV * (long)turns;
  rotationDir_global = (totalSteps >= 0) ? 1 : -1;
  rotationStepsRemaining = abs(totalSteps);
  performingRotation = true;
  running = true;
  waitingForContinue = false;

  Serial.printf("ROTATE %d turns (%ld steps)\n", turns, totalSteps);
  sendOk("ROTATING");
}

void setup() {
  Serial.begin(115200);
  // Lower speed for gentler, slower rotation
  stepper.setSpeed(4);

  // Start Wi-Fi Access Point
  WiFi.mode(WIFI_AP);
  WiFi.softAP(ssid, password);
  IPAddress IP = WiFi.softAPIP();
  Serial.println();
  Serial.print("Access Point: "); Serial.println(ssid);
  Serial.print("Password: "); Serial.println(password);
  Serial.print("Connect via HTTP: http://"); Serial.print(IP); Serial.println("/");

  // Start HTTP server
  server.on("/status", HTTP_GET, handleStatus);
  server.on("/start", HTTP_POST, handleStart);
  server.on("/rotate", HTTP_POST, handleRotate);
  server.on("/continue", HTTP_POST, handleContinue);
  server.on("/stop", HTTP_POST, handleStop);
  server.onNotFound([](){ server.send(404, "text/plain", "Not Found"); });
  server.begin();
  Serial.println("HTTP server started!");
}

void loop() {
  server.handleClient();
  processRotation();
}

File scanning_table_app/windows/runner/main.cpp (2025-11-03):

#include <flutter/dart_project.h>
#include <flutter/flutter_view_controller.h>
#include <windows.h>

#include "flutter_window.h"
#include "utils.h"

int APIENTRY wWinMain(_In_ HINSTANCE instance, _In_opt_ HINSTANCE prev,
                      _In_ wchar_t *command_line, _In_ int show_command) {
  // Attach to console when present (e.g., 'flutter run') or create a
  // new console when running with a debugger.
  if (!::AttachConsole(ATTACH_PARENT_PROCESS) && ::IsDebuggerPresent()) {
    CreateAndAttachConsole();
  }

  // Initialize COM, so that it is available for use in the library and/or
  // plugins.
  ::CoInitializeEx(nullptr, COINIT_APARTMENTTHREADED);

  flutter::DartProject project(L"data");

  std::vector<std::string> command_line_arguments =
      GetCommandLineArguments();

  project.set_dart_entrypoint_arguments(std::move(command_line_arguments));

  FlutterWindow window(project);
  Win32Window::Point origin(10, 10);
  Win32Window::Size size(1280, 720);
  if (!window.Create(L"scanning_table_app", origin, size)) {
    return EXIT_FAILURE;
  }
  window.SetQuitOnClose(true);

  ::MSG msg;
  while (::GetMessage(&msg, nullptr, 0, 0)) {
    ::TranslateMessage(&msg);
    ::DispatchMessage(&msg);
  }

  ::CoUninitialize();
  return EXIT_SUCCESS;
}

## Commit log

2025-10-23 chore: motor test
2025-10-23 chore: testing motor stepper and adding 3D files
    [Base_Plate_V1_PCBWay Community.stl, Gear_Plate_V1_PCBWay Community.stl, Leg_V1_PCBWay Community.stl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]
2025-10-25 chore: adaptors and connecting via WebSocket
    [Corn support.stl, Top_Plate_Modified.stl, Wheat_sorghum_soy Adapter.stl]
2025-11-03 chore: skeleton+style done
    [Paper Frame.stl]
2025-11-03 pcb: changes to working PCB
2025-11-06 chore: change to HTTP requests
    [Phone_Adapter_New.stl]
2025-11-13 chore: camera at maximum resolution
2025-11-14 chore: rename 3D files, app cameras compatibilities
    [Base_Plate.stl, Gear_Plate.stl, Leg.stl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]
2025-11-17 updates: bill of materials, new base plate and 3D printed quantities
    [Base_Plate.stl]
2025-11-20 chore: PCB update
2025-11-24 pcb: change the power source voltage to 9V
2025-11-25 3D: added the modified top plate
    [Top_Plate_Modified_Mini.stl]
2025-11-25 3D removing unused 3D files
    [Corn support.stl, Top_Plate_Modified.stl, Wheat_sorghum_soy Adapter.stl]
2026-03-06 3d files modified to rotate table, not phone
    [Base_Plate(1).stl, Base_Plate.stl, Gear_Plate (1).stl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]
2026-05-21 chore: image acquisition hardware
    [Base.stl, Base_Plate(1).stl, Gear_Plate (1).stl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]
2026-06-02 chore: Camera Properties and Geometry Estimation pt. 1
2026-06-02 chore: fixing synthetic plate size
2026-07-01 chore: images correctly taken, need to re-implement geometry and camera estimations
2026-07-03 chore: ALMOST there, the real cameras are being registered, but very badly
2026-07-03 chore: almost, almost
    [sparse_cloud.ply]
2026-07-03 chore: working for set_1. I'll re-take the images to better frame the board
    [sparse_cloud.ply]
2026-07-03 chore: fixing the virtual camera still in the last sparse model
    [sparse_cloud.ply]
2026-07-03 chore: section 2.4.1. Camera Properties and Geometry Estimation, done
    [sparse_cloud.ply]
2026-07-07 chore: Dense Point Cloud Reconstruction done
    [dense_raw.ply]
2026-07-07 chore: cropping
    [cropped.ply]
2026-07-07 chore: registration and merging
    [merged.ply]
2026-07-08 chore: meshing
    [mesh.ply]
2026-07-09 chore: texturing
    [mesh.ply, textured_vertex_colors.ply]
2026-07-10 chore: whole pipeline
    [cropped.ply, dense_raw.ply, merged.ply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]
2026-07-15 chore: modifications due to white light
    [mesh.ply, textured.ply]
2026-07-15 chore: updates on README and 3D files
    [Base.stl, Base_plate.stl, KNOB.STL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]
2026-07-17 fixing uneven plate and thin objects in meshes
    [mini_PC.ply]
2026-07-20 video and readme review
    [flower_PC.ply, straw_PC.ply]
2026-08-25 bringing cpu back in SfM for database building
    [flower_PC.ply, mini_PC.ply, straw_PC.ply]
2026-10-04 Robust geometry and orbit filling logic added
    [mesh.ply]
